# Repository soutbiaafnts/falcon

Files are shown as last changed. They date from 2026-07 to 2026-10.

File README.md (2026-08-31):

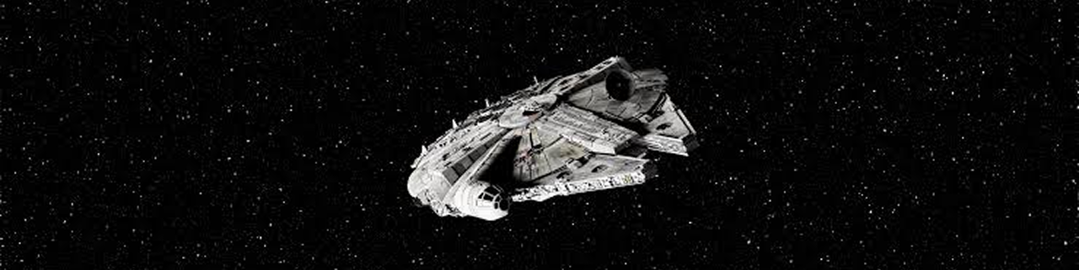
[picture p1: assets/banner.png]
millennium falcon


<h1 align="center">FALCON</h1>

<div align="center">





</div>

## Índice

- [Introdução](#1-introdução)
- [Problema de Pesquisa](#2-problema-de-pesquisa)
- [Hipóteses](#3-hipóteses)
- [Objetivo Geral](#4-objetivo-geral)
- [Objetivos Específicos](#5-objetivos-específicos)
- [Requisitos do Projeto](#6-requisitos-do-projeto)
- [Visão Geral do Funcionamento](#7-visão-geral-do-funcionamento)
- [Arquitetura Mecânica](#8-arquitetura-mecânica)
- [Quantidade de Compartimentos](#9-quantidade-de-compartimentos)
- [Arquitetura Eletrônica](#10-arquitetura-eletrônica)
- [Tecnologias](#11-tecnologias)
- [Arquitetura do Software](#12-arquitetura-de-software)
- [Arquitetura Baseada em Eventos](#13-arquitetura-baseada-em-eventos)
- [Máquina de Estados](#14-máquina-de-estados)
- [Engenharia de Software](#15-engenharia-de-software)
- [Organização da Equipe](#16-organização-da-equipe)
- [Indicadores de Validação](#17-indicadores-de-validação)
- [Critérios de Aceite](#18-critérios-de-aceite)
- [Preparação para o TCC](#19-preparação-para-o-tcc)
- [Conclusão](#20-conclusão)

---

# 1. Introdução

O Falcon é um sistema embarcado para dispensação automática de medicamentos desenvolvido com foco na autonomia de idosos e na redução da necessidade de acompanhamento constante por cuidadores.

O projeto integra conceitos de Sistemas Embarcados, Internet das Coisas (IoT), Automação, Engenharia de Software, Robótica e Modelagem 3D para desenvolver um dispositivo de baixo custo, modular e preparado para futuras expansões.

A Iniciação Científica terá como foco o desenvolvimento de um protótipo funcional capaz de armazenar medicamentos, realizar a dispensação automática em horários programados, registrar eventos e fornecer uma interface simples para pacientes e cuidadores.

O Trabalho de Conclusão de Curso será uma evolução natural deste projeto, incorporando comunicação via Internet e geração de relatórios.

---

# 2. Problema de Pesquisa

**Como a utilização de um dispensador automático de medicamentos influencia a autonomia de idosos e a necessidade de intervenção dos cuidadores na administração medicamentosa?**

---

# 3. Hipóteses

## Hipótese Técnica (validada na IC)

O Falcon será capaz de:

- armazenar medicamentos;
- dispensá-los automaticamente nos horários programados;
- registrar a retirada ou ausência de retirada dos medicamentos;
- fornecer informações suficientes para apoiar o acompanhamento da administração medicamentosa.

## Hipótese de Impacto (a ser explorada futuramente)

A utilização do Falcon tende a aumentar a autonomia dos idosos e reduzir a necessidade de acompanhamento constante por parte dos cuidadores.

---

# 4. Objetivo Geral

Projetar, desenvolver e validar um protótipo funcional de um sistema embarcado para dispensação automática de medicamentos, visando avaliar seu potencial para aumentar a autonomia dos idosos e reduzir a necessidade de intervenção constante dos cuidadores.

---

# 5. Objetivos Específicos

- Projetar a estrutura mecânica utilizando modelagem e impressão 3D.
- Desenvolver a arquitetura eletrônica baseada em ESP32.
- Implementar o mecanismo automático de dispensação.
- Desenvolver um sistema de configuração de horários.
- Implementar sensores para monitoramento do funcionamento.
- Detectar automaticamente a retirada do copo contendo o medicamento.
- Registrar localmente todos os eventos de dispensação.
- Desenvolver uma interface simples para pacientes e cuidadores.
- Construir uma arquitetura de software modular preparada para futura integração com sistemas IoT.

---

# 6. Requisitos do Projeto

## Requisitos Funcionais

O Falcon deverá:

- armazenar medicamentos em compartimentos independentes;
- permitir configuração de horários;
- emitir alerta sonoro no horário programado;
- liberar apenas o medicamento correspondente ao horário atual;
- impedir acesso ao estoque pelo paciente;
- detectar retirada do copo;
- registrar retirada ou ausência de retirada;
- impedir a dispensação de outros medicamentos em ausência de retirada;
- exibir informações em display;
- manter configurações mesmo após desligamento.

## Requisitos Não Funcionais

O sistema deverá:

- possuir baixo custo;
- ser compacto;
- utilizar componentes facilmente encontrados;
- permitir manutenção simples;
- possuir arquitetura modular;
- facilitar futuras expansões;
- utilizar componentes preparados para IoT;
- possuir alimentação por bateria e fonte externa.

---

# 7. Visão Geral do Funcionamento

## Abastecimento

O cuidador:

1. desbloqueia o compartimento utilizando uma chave física;
2. abastece os compartimentos;
3. configura os horários;
4. fecha novamente o sistema.

---

## Operação

Durante o funcionamento:

1. O Falcon monitora continuamente o horário através do RTC.
2. Quando chega o horário programado:
   - o buzzer é acionado;
   - o display informa que há um medicamento disponível.
3. O paciente pressiona o botão de confirmação.
4. O mecanismo gira até o compartimento correspondente.
5. O medicamento é conduzido por um funil até um copo apoiado sobre uma célula de carga.
6. Quando o paciente retira o copo:
   - o Falcon registra o evento;
   - encerra o alarme.
7. Caso o copo não seja retirado:
   - o alarme é repetido periodicamente.
8. Após 30 minutos sem retirada:
   - registra "medicamento não retirado";
   - considera o horário encerrado e trava o próximo evento programado até que a retirada seja detectada.

---

# 8. Arquitetura Mecânica

O Falcon será composto por:
- estrutura cilíndrica fixa;
- haste central;
- conjunto de palhetas acopladas à haste;
- compartimentos independentes;
- porta inferior de dispensação;
- funil direcionador;
- suporte para copo;
- compartimento eletrônico.

A haste central será movimentada por um servo motor 360˚.

Cada posição angular corresponderá a um compartimento.

---

# 9. Quantidade de Compartimentos

Inicialmente será adotado:

**12 compartimentos.**

Justificativas:

- reduz complexidade mecânica;
- reduz tempo de impressão;
- reduz torque necessário;
- facilita validação;
- mantém o protótipo compacto.

No TCC poderá ser ampliado para 28 compartimentos (estoque semanal), sem necessidade de grandes alterações no software.

---

# 10. Arquitetura Eletrônica

## Unidade de Processamento

ESP32 DevKit V1

---

## Controle de Tempo

RTC DS3231

---

## Interface

Display OLED 128x64 I²C

Botões:

- cima
- baixo
- confirmar
- voltar

---

## Atuadores

- buzzer ativo;
- servo motor 360˚.

---

## Sensores

- célula de carga + HX711;
- sensor Hall e ímã de neodímio para posição HOME.

---

## Alimentação

- fonte externa;
- bateria recarregável;
- conversor DC-DC.

## Valores

- [ESP32 DevKit V1](https://www.mercadolivre.com.br/esp32-30-pino-doit-devkit-com-esp32-wroom-32-wifi-bluetooth/p/MLB2038780923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;EQ:ESP32%20NODEMCU;EQ:ESP32%20WROOM&be_origin=backend&position=1&search_layout=grid&type=pad&tracking_id=4d1debf9-8a6a-42a1-9800-cc507a36f91b&ad_domain=VQCATCORE_LST&ad_position=1&ad_click_id=ZTYwMzdhODEtMTA4Yi00Y2VhLWEyMmYtZTY1MDQ5N2Q4Y2Q1): R$ 32,70
- [RTC DS3231](https://www.mercadolivre.com.br/modulo-real-time-rtc-ds3231/p/MLB41384231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;EQ:MODULO%20RTC;EQ:RTC%20DS3231%20MODULO;EQ:MODULO%20RTC%203231;EQ:RTC%20DS3231%20ARDUINO&be_origin=backend&position=1&search_layout=grid&type=pad&tracking_id=c17a0cc6-e659-4e7b-901a-14bb75c5008c&ad_domain=VQCATCORE_LST&ad_position=1&ad_click_id=N2ExN2VmZjctZGYzOC00YzhkLTgxMzYtOGUyZDRiMzZlN2Rj): R$ 19,19
- [Display OLED 128x64 I²C](https://www.mercadolivre.com.br/modulo-display-oled-tela-096-i2c-ssd1306-lcd-arduino-pic/up/MLBU773901547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;EQ:SSD1306;EQ:OLED%20096%20I2C;EQ:DISPLAY%20OLED%20128X64%20I2C%20AZUL;EQ:DISPLAY%20OLED%20128X64%20I2C&be_origin=backend&position=1&search_layout=grid&type=pad&tracking_id=63dfb182-08c7-4a85-abdb-91708b91d7fa&ad_domain=VQCATCORE_LST&ad_position=1&ad_click_id=ZTk4MDMwMDMtZDIwNC00YTVmLThhZmUtYmNkZDAzMGViN2Ji): R$ 17,98
- [4 botões](https://www.mercadolivre.com.br/kit-com-500--chave-tactil-6x6x5mm-4t-180-graus/up/MLBU3226780648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): ≃ R$ 0,38
- [Buzzer ativo](https://www.mercadolivre.com.br/buzzer-ativo-5v-sinal-beep-arduino-raspberry-som/up/MLBU3872444152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;EQ:BUZZER%205V;EQ:BUZZER%20ATIVO%205V&be_origin=backend&position=3&search_layout=grid&type=pad&tracking_id=111eae54-e435-4e59-ac77-3eb81cb5ed3e&ad_domain=VQCATCORE_LST&ad_position=3&ad_click_id=YzRmZGM3MmEtZGNlNi00NmRjLWIzN2MtYzQzYjFlZDcwNGEz): R$ 7,92
- [Servo motor 360˚](https://www.mercadolivre.com.br/servo-motor-tower-pro-mg90d-360-graus/p/MLB68229896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): R$ 33,44
- [Célula de carga + HX711](https://www.mercadolivre.com.br/1-celula-de-carga-1kg-sensor-peso--1-modulo-hx711-arduino/up/MLBU750020937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;EQ:CELULA%20CARGA%2010KG&be_origin=backend&position=1&search_layout=grid&type=pad&tracking_id=721b0252-50d7-46a9-80fa-e40b20ddbfcb&ad_domain=VQCATCORE_LST&ad_position=1&ad_click_id=YmZmOTcxMTEtNDdkOS00NjNmLThlYzItYTA3MjZmMjcyMThm): R$ 27,92
- [Sensor Hall](https://www.mercadolivre.com.br/kit-10-sensores-magnetico-de-efeito-hall-ss41f-41f-c-nfe/up/MLBU755274844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;EQ:SENSOR%20EFEITO%20HALL&be_origin=backend&position=3&search_layout=grid&type=pad&tracking_id=04c8adaf-76b5-4a32-be34-4bbb23488635&ad_domain=VQCATCORE_LST&ad_position=3&ad_click_id=Yjc0OWZiODItYjc0Yi00NTRjLWE1MzUtYzlmMTI1ZWI4MmQ0): R$ 2,19
- [Imã de Neodímio](https://www.mercadolivre.com.br/ima-de-neodimio-10x2-redondo-pequeno-10mm-x-2mm-n35-10pcs/p/MLB32490961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): R$ 2,22
- [Fonte externa](): R$
- [Bateria recarregável](): R$
- [Conversor DC-DC](): R$

**Total:** ≃ R$ 143,94

---

# 11. Tecnologias

## Linguagem

C++

Framework Arduino para ESP32.

Motivos:

- ampla documentação;
- grande quantidade de bibliotecas;
- maior desempenho;
- facilidade de manutenção;
- alta escalabilidade.

---

# 12. Arquitetura de Software

O software será dividido em módulos independentes.

- Display
- RTC
- Motor
- Buzzer
- Botões
- Célula de carga
- Configurações
- Persistência
- Registro de eventos
- Agendador
- Máquina de Estados

Cada módulo possuirá apenas uma responsabilidade.

---

# 13. Arquitetura Baseada em Eventos

O software será orientado por eventos.

Exemplos:

## Evento: Horário Alcançado

- ligar buzzer;
- atualizar display;
- aguardar confirmação.

## Evento: Confirmação

- posicionar compartimento;
- liberar medicamento.

## Evento: Copo Retirado

- registrar evento;
- desligar buzzer;
- atualizar display.

Essa abordagem facilita manutenção e futuras expansões.

---

# 14. Máquina de Estados

Fluxo simplificado:

Inicialização

↓

Busca posição HOME

↓

Modo de espera

↓

Horário alcançado

↓

Alarme

↓

Confirmação

↓

Dispensação

↓

Aguardando retirada

↓

Registro

↓

Retorno ao modo de espera

---

# 15. Engenharia de Software

O projeto adotará princípios modernos de desenvolvimento.

## SOLID

Principalmente:

- Single Responsibility Principle;
- Open/Closed Principle.

---

## Clean Code

- nomes claros;
- funções pequenas;
- baixo acoplamento;
- alta coesão.

---

## Git

Controle de versão desde o primeiro dia.

Branches sugeridas:

- main
- software
- hardware
- mecanica
- testes

---

## Kanban

Organização das atividades:

- Backlog
- A Fazer
- Em Desenvolvimento
- Em Teste
- Concluído

---

## Sprints

Reuniões semanais para integração dos módulos.

---

# 16. Organização da Equipe

## Desenvolvimento de Software - Bianca

Responsável por:

- arquitetura;
- programação;
- integração;
- testes.

---

## Eletrônica - Wanessa

Responsável por:

- circuito;
- sensores;
- motores;
- alimentação;
- montagem.

---

## Mecânica - Alany

Responsável por:

- modelagem CAD;
- impressão 3D;
- testes mecânicos;
- ajustes estruturais.

---

# 17. Indicadores de Validação

O Falcon será avaliado através de indicadores objetivos.

- funcionamento correto da dispensação;
- precisão do posicionamento;
- funcionamento contínuo sem travamentos;
- registro correto dos eventos;
- tempo de resposta do sistema;
- custo final do protótipo;
- consumo energético;
- facilidade de configuração.

---

# 18. Critérios de Aceite

O Falcon será considerado funcional quando:

- localizar corretamente a posição HOME;
- posicionar qualquer compartimento corretamente;
- dispensar o medicamento correspondente;
- detectar retirada do copo;
- registrar corretamente os eventos;
- manter horários após desligamento;
- operar continuamente durante testes prolongados.

---

# 21. Preparação para o TCC

A arquitetura será preparada para reutilização.

Na IC:

Sistema Embarcado

↓

Persistência Local

↓

Interface Local

No TCC serão adicionados:

- Wi-Fi;
- Relatórios;
- Estatísticas;
- Notificações;

Nenhum desses recursos exigirá reescrever o núcleo do software.

---

# 21. Conclusão

O Falcon será desenvolvido como um **produto de engenharia**, e não apenas como um protótipo acadêmico. O projeto seguirá uma abordagem baseada em levantamento de requisitos, desenvolvimento incremental, modularização de hardware e software, integração contínua e validação por indicadores objetivos.

Essa estratégia permitirá que a Iniciação Científica entregue um sistema funcional, confiável e tecnicamente consistente, ao mesmo tempo em que estabelece uma base sólida para o Trabalho de Conclusão de Curso. A evolução futura poderá concentrar esforços na conectividade e análise de dados, preservando toda a arquitetura desenvolvida na IC e reduzindo significativamente o retrabalho.

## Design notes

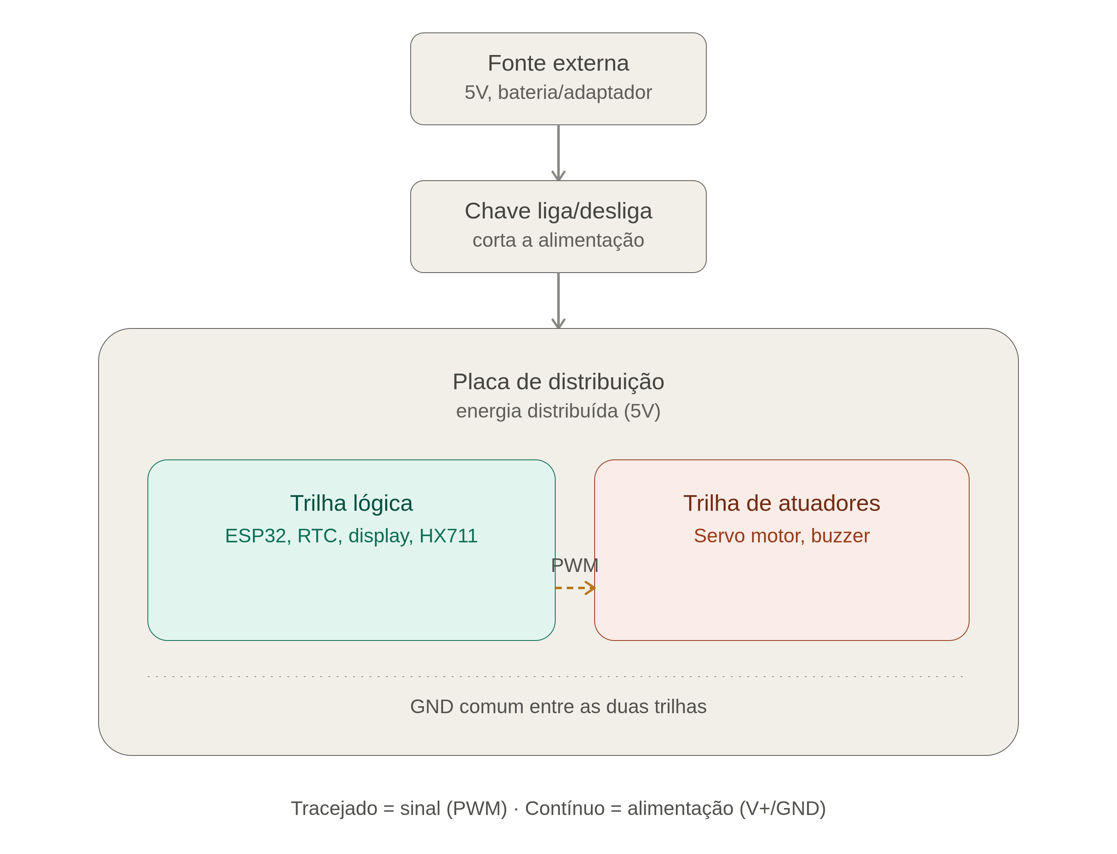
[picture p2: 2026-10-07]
assets/falcon_power_signal_distribution.png

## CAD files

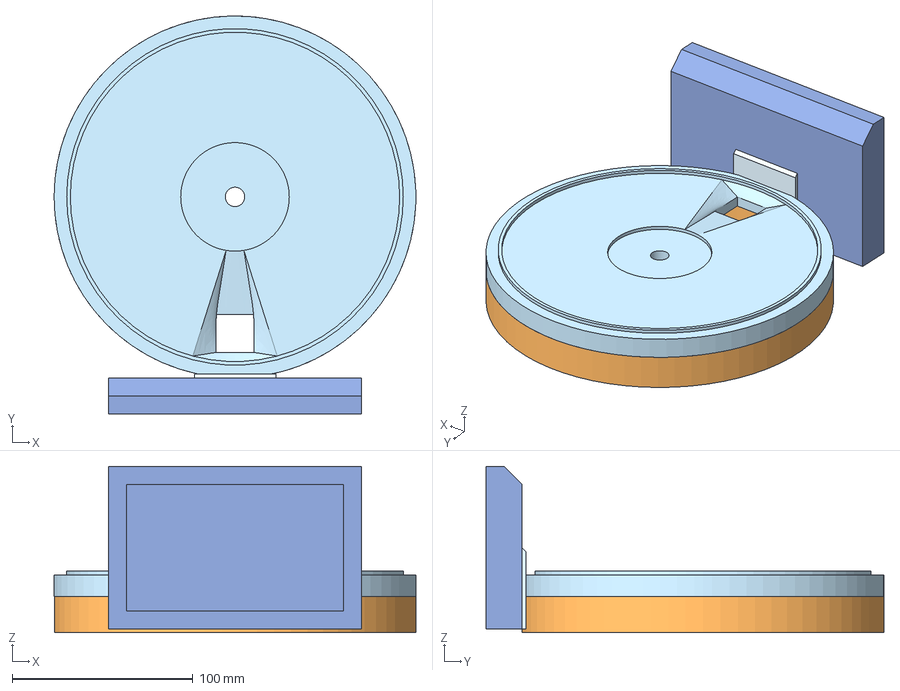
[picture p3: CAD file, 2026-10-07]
assets/3d-models/01_Base.3mf
200.0 x 220.0 x 92.0 mm

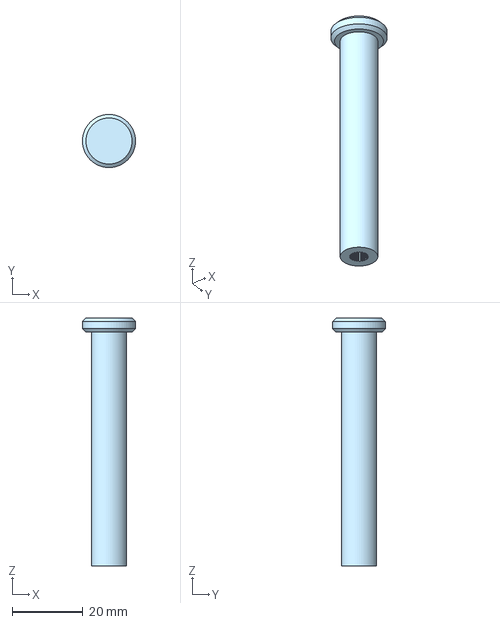
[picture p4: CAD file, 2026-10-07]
assets/3d-models/04_Haste.3mf
15.0 x 15.0 x 70.0 mm

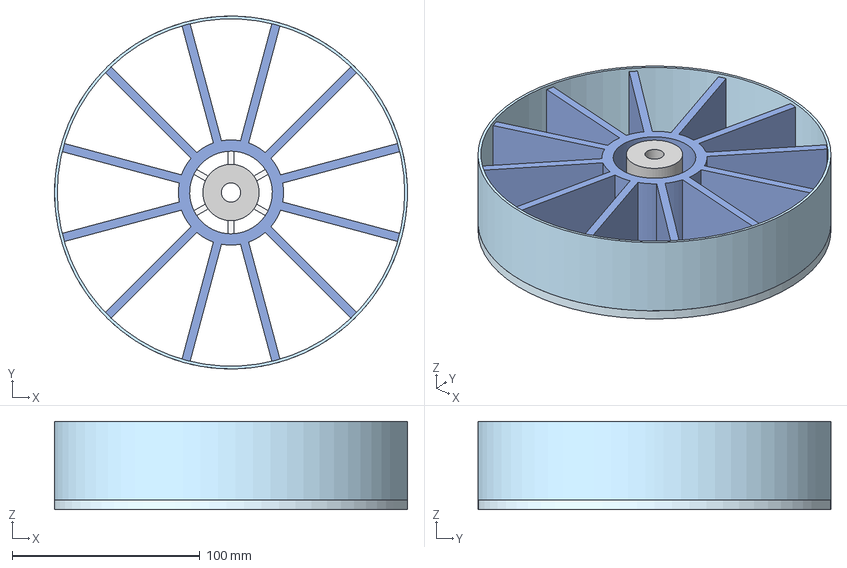
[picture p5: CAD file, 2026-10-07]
assets/3d-models/05_Rotor_Distribuidor.3mf
188.0 x 187.9 x 47.0 mm

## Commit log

2026-07-18 fix(readme): movido para a pasta principal
2026-10-07 initial commit (esp32)
    [01_Base.3mf, 04_Haste.3mf, 05_Rotor_Distribuidor.3mf]
